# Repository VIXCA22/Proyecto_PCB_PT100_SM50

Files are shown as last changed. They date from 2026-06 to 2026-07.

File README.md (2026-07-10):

# Tarjeta de acondicionamiento de señales PT100 y SM-50

Diseño e implementación de una tarjeta de acondicionamiento de señales para sensores de torque y temperatura en un motor de inducción trifásico del LabCES. La PCB adapta las señales de un sensor de temperatura PT100 y un sensor de torque SM-50 para facilitar su adquisición y monitoreo dentro de un sistema de medición.

## Objetivo

Diseñar e implementar una tarjeta de circuito impreso que permita acondicionar y adaptar las señales provenientes de los sensores de torque y temperatura de un motor de inducción utilizado en el LabCES, con el propósito de facilitar su correcta adquisición y monitoreo para analizar el desempeño del motor.

## Objetivos específicos

1. Comprender los fundamentos básicos del diseño de tarjetas de circuito impreso y su aplicación al acondicionamiento de señales usando KiCad.
2. Verificar el funcionamiento de los sensores de torque y temperatura mediante simulaciones y pruebas experimentales.
3. Diseñar una PCB que integre el circuito necesario para acondicionar las señales de los sensores.
4. Implementar y probar el prototipo, evaluando su desempeño dentro del sistema de medición del motor de inducción en el LabCES.
5. Mantener un repositorio Git con archivos de diseño electrónico, documentación técnica e historial de desarrollo.

## Vista del diseño

### Esquemático KiCad

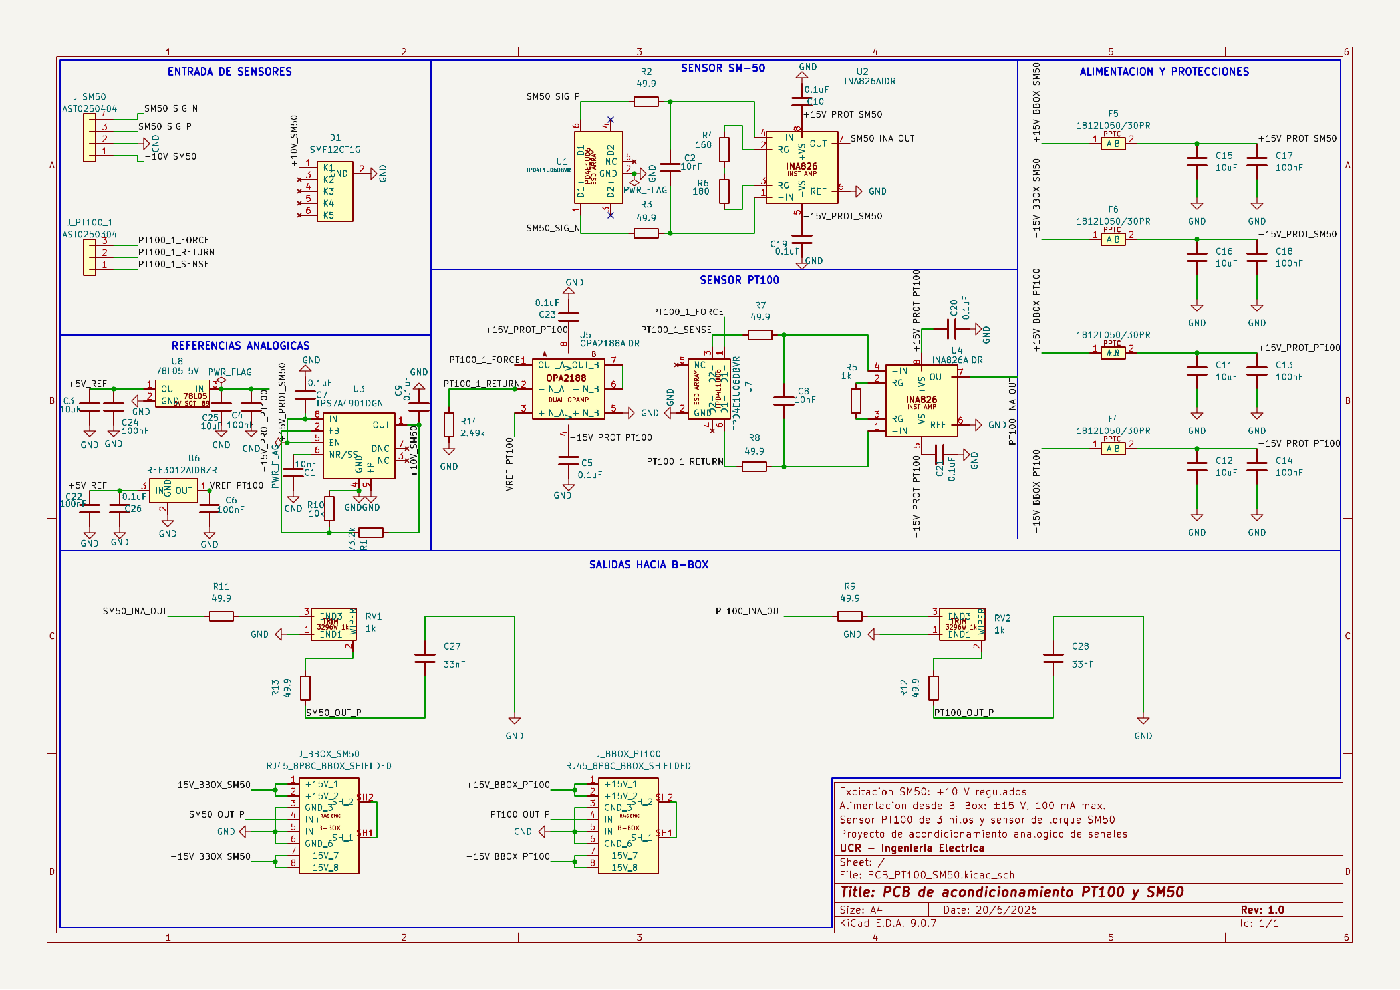
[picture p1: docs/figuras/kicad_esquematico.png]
Esquemático KiCad


### PCB en KiCad

<p align="center">
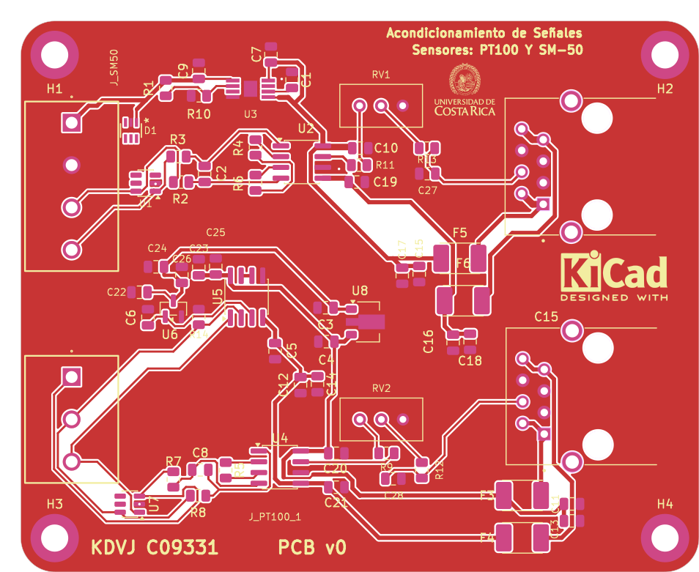
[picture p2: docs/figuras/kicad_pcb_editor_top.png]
PCB 2D
  
</p>

### PCB 3D

<p align="center">
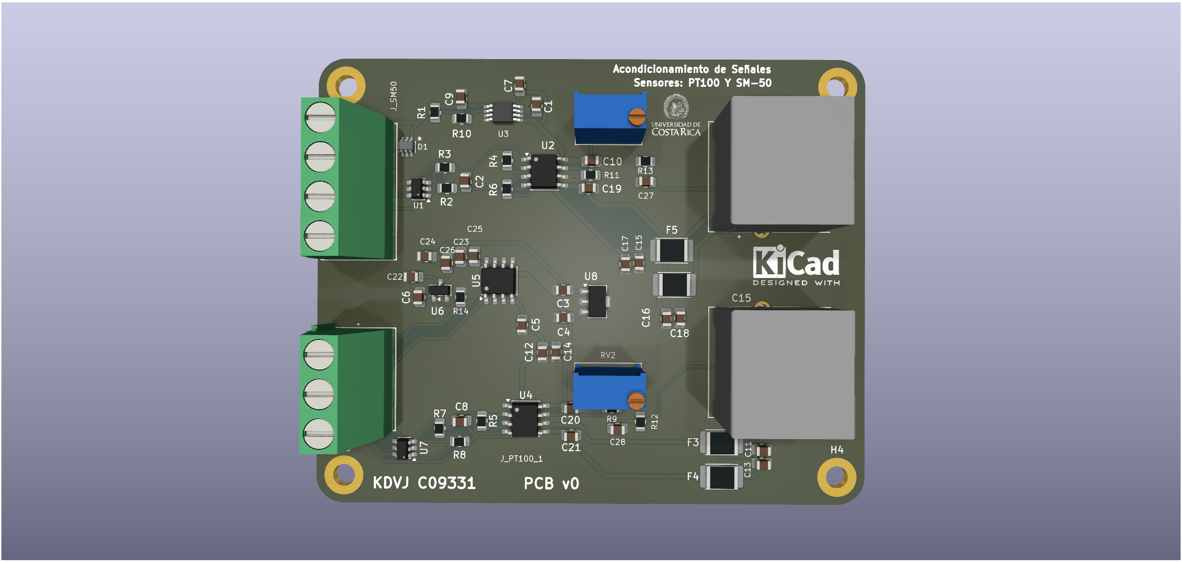
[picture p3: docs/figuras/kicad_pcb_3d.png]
PCB 3D
  
</p>

## Diagrama de bloques

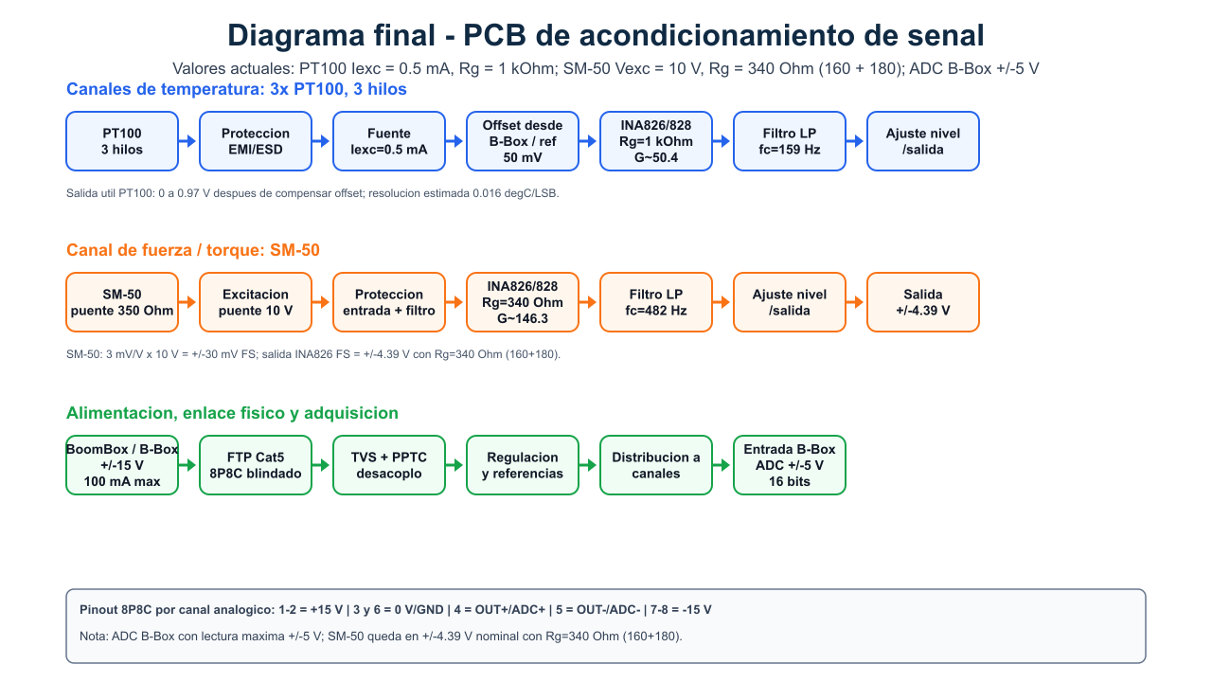
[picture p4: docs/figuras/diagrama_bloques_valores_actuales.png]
Diagrama de bloques


Nota de adquisicion: la lectura maxima del ADC de la B-Box se toma como +/-5 V (10 V de span), por lo que la salida bipolar nominal del SM-50 se mantiene en +/-4.39 V para conservar margen de medicion.

## Simulaciones

### Canal PT100

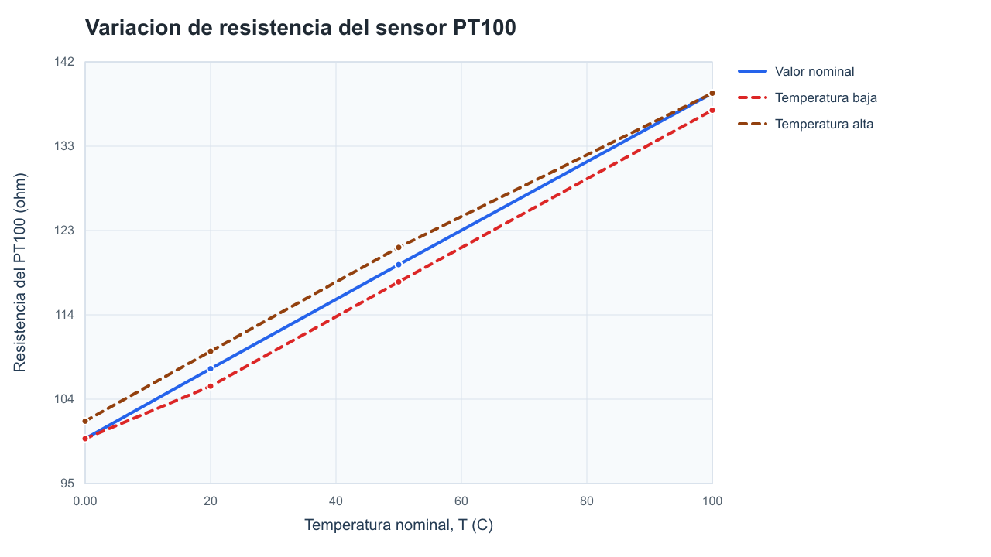
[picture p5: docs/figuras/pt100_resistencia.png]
Resistencia PT100


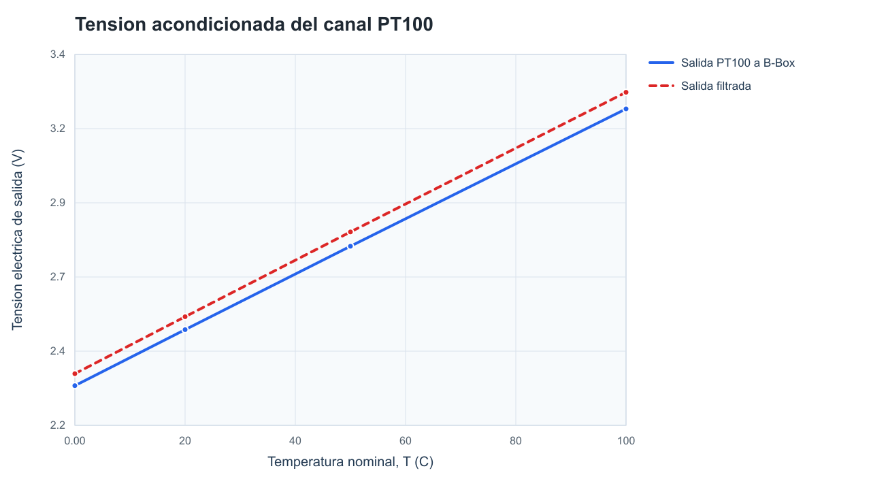
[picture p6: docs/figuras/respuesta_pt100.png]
Respuesta PT100


### Canal SM-50

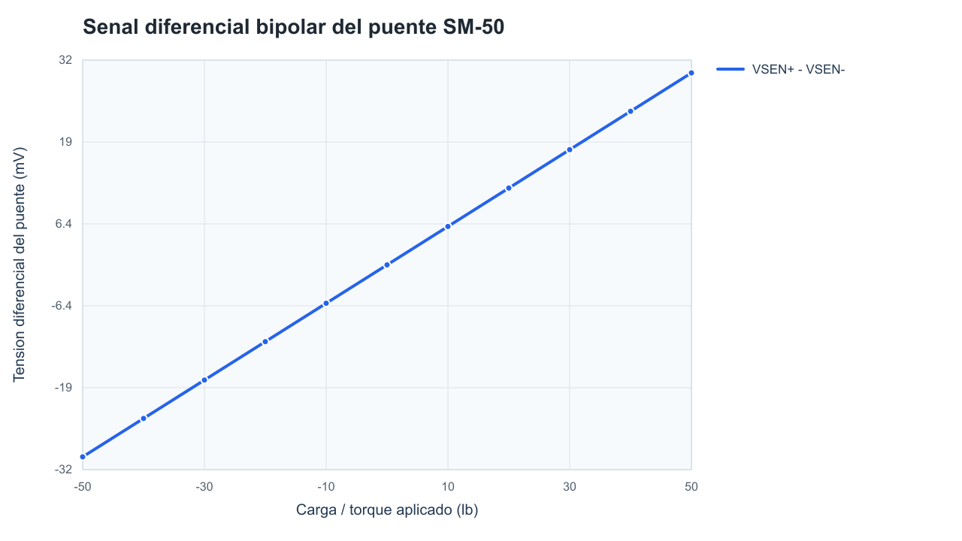
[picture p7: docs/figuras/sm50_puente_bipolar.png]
Puente SM-50 bipolar


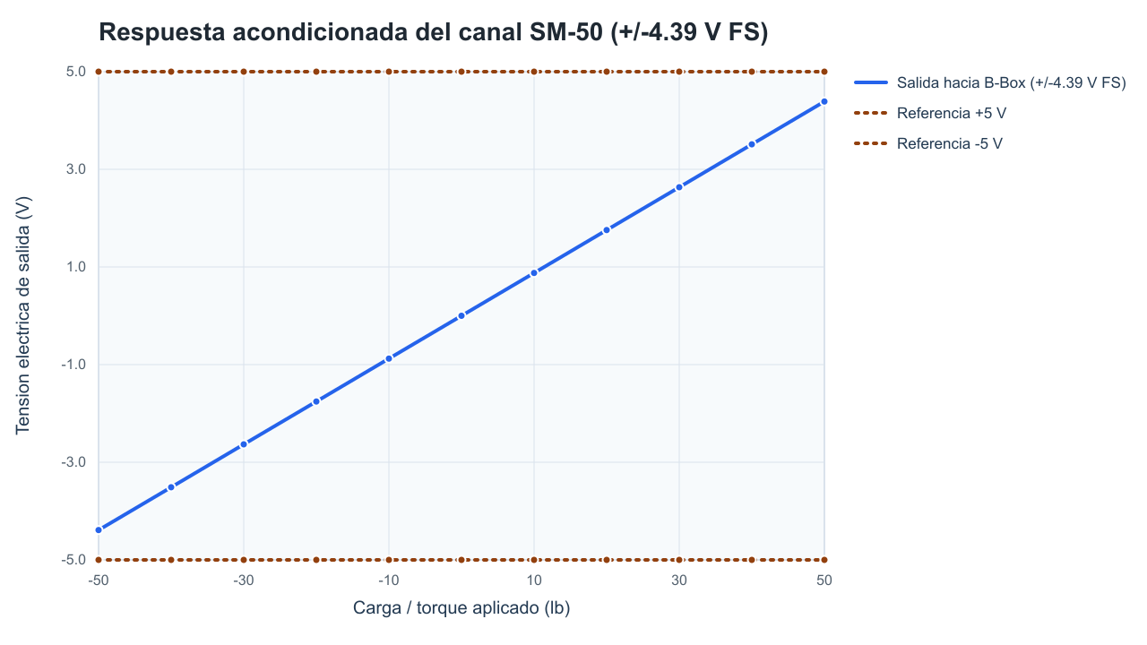
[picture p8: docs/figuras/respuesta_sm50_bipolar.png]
Respuesta SM-50 bipolar


### Esquemáticos LTspice

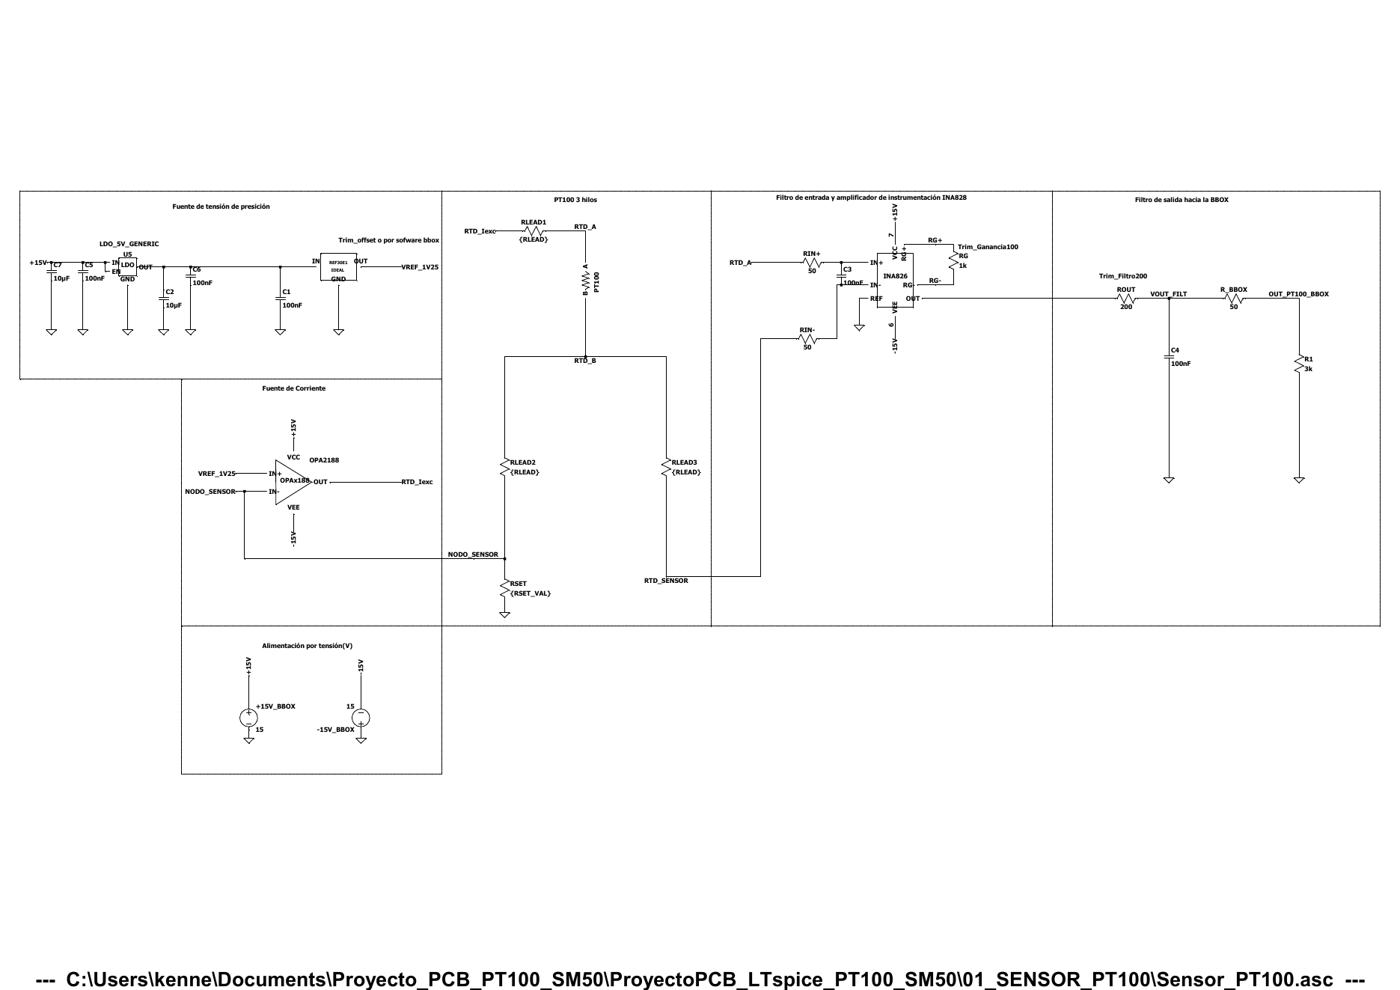
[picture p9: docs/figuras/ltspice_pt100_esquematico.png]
LTspice PT100


[PDF PT100](docs/figuras/ltspice_pt100_esquematico.pdf)

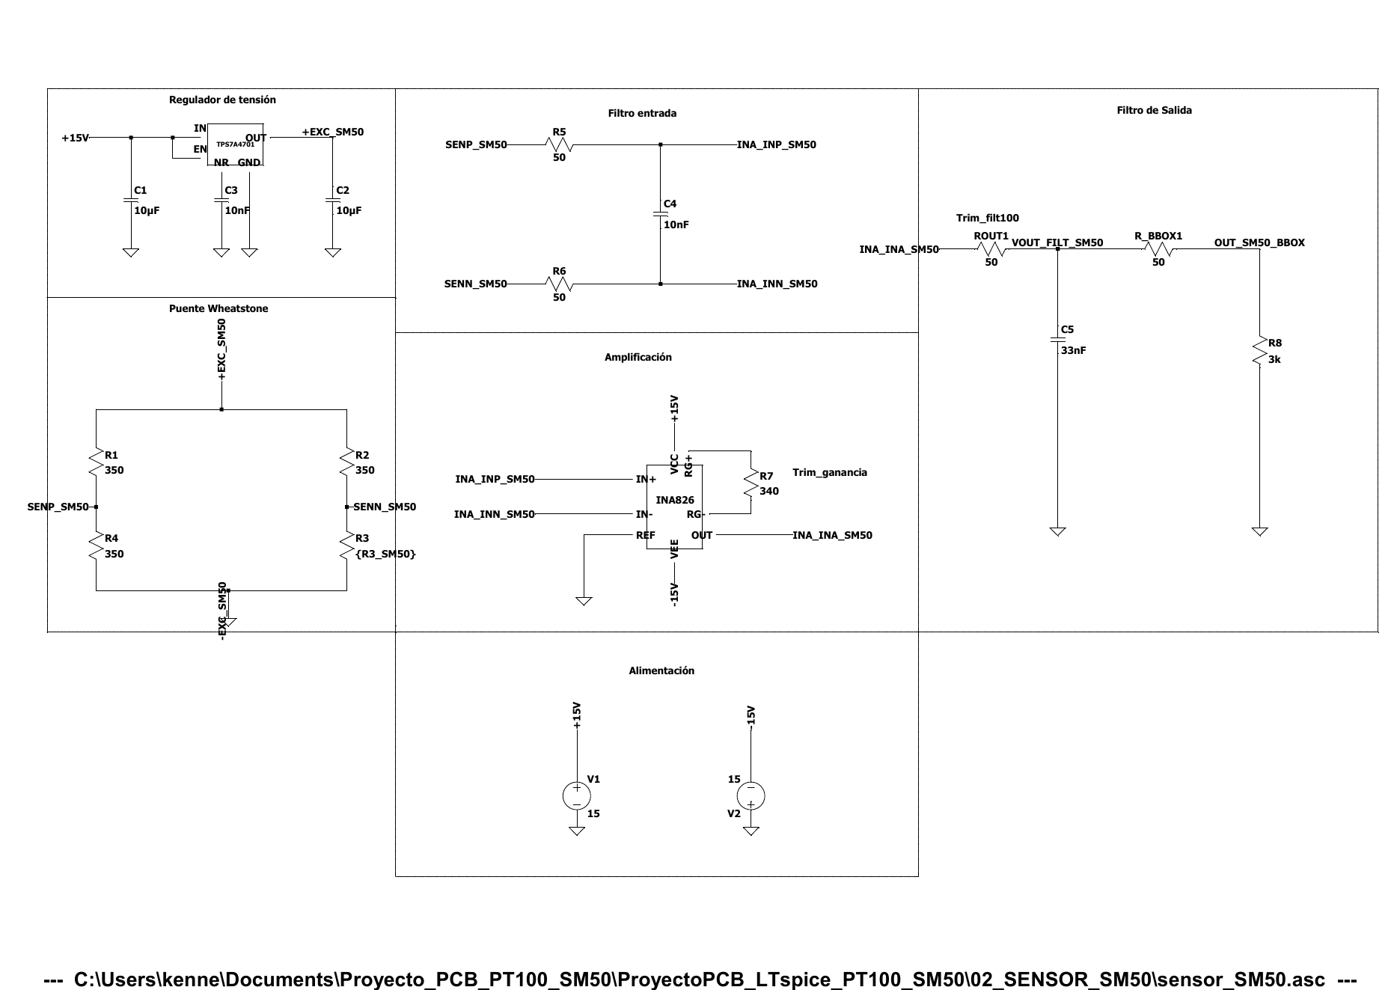
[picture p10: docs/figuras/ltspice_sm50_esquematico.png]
LTspice SM-50


[PDF SM-50](docs/figuras/ltspice_sm50_esquematico.pdf)

## Estructura del repositorio

| Ruta | Contenido |
| --- | --- |
| `PCB_PT100_SM50/` | Proyecto KiCad principal: esquemático, PCB, librerías locales, footprints y modelos 3D. |
| `ProyectoPCB_LTspice_PT100_SM50/` | Simulaciones LTspice de los canales PT100 y SM-50. |
| `docs/figuras/` | Imágenes/PDF del esquemático, PCB, vista 3D, LTspice y gráficas. |
| `docs/simulacion/` | CSV, resumen numérico y cálculos finales usados para las gráficas y tablas. |
| `docs/validacion/` | Reportes finales ERC/DRC. |
| `docs/fabricacion/` | ZIP Gerber final con archivo de taladros. |
| `docs/resumen/` | Resumen ejecutivo final del proyecto. |
| `docs/poster/` | Póster final usado para la presentación del proyecto. |
| `docs/bitacora/` | Bitácora actualizada del proceso, en PDF y fuente LaTeX. |
| `docs/referencias/` | Resumen de verificación de footprints y documentos de entrega conservados. |
| `scripts/` | Script para regenerar figuras de simulación y vistas documentales LTspice. |

## Estado final

- KiCad ERC: `0` errores, `0` advertencias.
- KiCad DRC: `0` violaciones, `0` pads desconectados, `0` errores de footprints.
- Paridad esquemático-PCB: `0` problemas.
- ZIP para fabricar: `docs/fabricacion/PCB_PT100_SM50_GERBERS_CON_DRILL.zip`.
- Reportes: `docs/validacion/erc_final_20260626.rpt` y `docs/validacion/drc_final_20260626.rpt`.

## Cómo revisar

1. Abrir `PCB_PT100_SM50/PCB_PT100_SM50.kicad_pro` en KiCad 9.
2. Ejecutar ERC desde el editor esquemático.
3. Ejecutar DRC con comprobación de paridad esquemático-PCB desde el editor PCB.
4. Revisar las simulaciones en `ProyectoPCB_LTspice_PT100_SM50/`.
5. Subir a fabricación el ZIP `docs/fabricacion/PCB_PT100_SM50_GERBERS_CON_DRILL.zip` si se requiere fabricar esta revisión.

## Documentación

- [Reporte formal IEEE PCB PT100/SM-50](docs/reporte_ieee/ReporteFormalPCB_PT100_SM50.pdf)
- [Informe de desarrollo del proyecto](docs/INFORME_DESARROLLO_PROYECTO.md)
- [Resumen ejecutivo](docs/resumen/ResumenEjecutivoKDVJC09331.pdf)
- [Proceso de diseño y trazabilidad](docs/PROCESO_DISENO_TRAZABILIDAD.md)
- [Bitácora actualizada del proyecto](docs/bitacora/bitacora_PCB_actualizada_27_06_2026.pdf)
- [Póster final](docs/poster/vizcaino-jimenez.pdf)
- [Validación final](docs/VALIDACION.md)
- [Referencias técnicas y footprints](docs/REFERENCIAS_TECNICAS.md)

## Herramientas

- KiCad 9.0.7
- LTspice
- Python 3 para generar figuras documentales
- Git / GitHub

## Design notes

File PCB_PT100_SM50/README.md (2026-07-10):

# Proyecto KiCad - PCB PT100 y SM-50

Esta carpeta contiene el diseno KiCad principal de la tarjeta de acondicionamiento de senales para sensores PT100 y SM-50.

## Archivos principales

| Archivo o carpeta | Uso |
| --- | --- |
| `PCB_PT100_SM50.kicad_pro` | Proyecto KiCad principal. |
| `PCB_PT100_SM50.kicad_sch` | Esquematico del circuito de acondicionamiento. |
| `PCB_PT100_SM50.kicad_pcb` | Layout de la PCB. |
| `symbols/` | Librerias de simbolos locales. |
| `footprints/` | Huellas locales usadas por la PCB. |
| `3d/` | Modelos 3D vinculados a las huellas. |
| `bom/` | Lista de materiales y referencia de compra. |
| `docs/` | Imagenes y soporte visual del diseno. |
| `outputs/` | Reportes de validacion generados por KiCad. |

## Estado de validacion

El cierre de validacion documentado fue generado con KiCad 9 y no reporta violaciones:

```text
../docs/validacion/erc_final_20260626.rpt
../docs/validacion/drc_final_20260626.rpt
```

La carpeta `outputs/` conserva reportes locales intermedios del PCB. Los reportes anteriores con warnings eran de sincronizacion de librerias, no de conexion electrica. Se registro la libreria faltante `ProyectoPCB` y se dejo la regla `lib_symbol_mismatch` en `ignore` porque varios simbolos fueron ajustados localmente para el esquematico.

## Uso rapido

1. Abrir `PCB_PT100_SM50.kicad_pro` en KiCad 9.
2. Revisar el esquematico y correr ERC.
3. Revisar el PCB y correr DRC antes de fabricar.
4. Usar las librerias locales incluidas en `sym-lib-table` y `fp-lib-table`.

## Nota sobre LTspice

Los archivos `.asy` y `.lib` pertenecen a simulacion LTspice. No se deben importar como simbolos o footprints KiCad; para KiCad se usan `.kicad_sym`, `.kicad_mod` y modelos `.step/.wrl`.

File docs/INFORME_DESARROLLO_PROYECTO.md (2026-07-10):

# Informe de desarrollo del proyecto

Fecha de redacción: 2026-06-27.

## Proyecto

Este proyecto consistió en diseñar y documentar una tarjeta de circuito impreso para el acondicionamiento de las señales de un sensor de temperatura PT100 y un sensor de carga/torque SM-50, pensada para integrarse al sistema de medición de un motor trifásico de inducción del LabCES. La tarjeta se planteó como una etapa intermedia entre los sensores instalados en el banco y la interfaz de adquisición, por lo que el diseño se enfocó en entregar señales de voltaje limpias, protegidas y dentro de rangos útiles para la B-Box o el sistema de adquisición disponible.

El punto de partida fue una investigación previa de LabCES orientada al cálculo de eficiencia de motores mediante el estándar IEEE 112, método C. En ese trabajo se identificó la necesidad de medir temperatura, velocidad, potencia y carga para estimar la eficiencia del motor bajo distintos puntos de operación. También se documentó que la temperatura se midió con sensores RTD instalados en los bobinados del estator y que la señal de carga requería una revisión cuidadosa, ya que durante pruebas previas el comportamiento del sensor no fue suficientemente confiable. Por esa razón, esta PCB se trabajó como una mejora de acondicionamiento y documentación, no como una prueba experimental final del banco.

## Fuentes usadas

| Fuente | Uso en el proyecto |
| --- | --- |
| `Proyecto_PCB_TODO_con_referencias.zip/00_INDICE_DE_ARCHIVOS.txt` | Índice del paquete completo de referencias, memorias, capturas, datasheets y bibliografía. |
| `Proyecto_PCB_TODO_con_referencias.zip/00_REFERENCIAS_IMPORTANTES.txt` | Bibliografía principal en formato LaTeX/bibitem para defender el proyecto. |
| `Proyecto_PCB_TODO_con_referencias.zip/calculos_memorias/memoria_calculo_PCB0.docx` | Memoria preliminar de cálculo para PT100 y SM-50; usada para documentar la evolución de los parámetros. |
| `Proyecto_PCB_TODO_con_referencias.zip/referencias_bibliografia/fuentes_pcb_sensores_motor.pdf` | Marco bibliográfico sobre PCB de acondicionamiento, sensores de torque/temperatura y motores de inducción. |
| `Proyecto_PCB_TODO_con_referencias.zip/instrumentacion_puentes_adc/sloa034.pdf` | Referencia de TI para acondicionamiento de sensores resistivos en puente Wheatstone. |
| `Proyecto_PCB_TODO_con_referencias.zip/instrumentacion_puentes_adc/sboa247a.pdf` | Referencia de TI para amplificación de puentes de galgas extensiométricas en una sola alimentación. |
| `Proyecto_PCB_TODO_con_referencias.zip/instrumentacion_puentes_adc/an43f.pdf` | Nota de Analog Devices sobre circuitos de puente. |
| `Proyecto_PCB_TODO_con_referencias.zip/instrumentacion_puentes_adc/an96fa.pdf` | Nota de Analog Devices sobre medición de puentes con ADC delta-sigma y consideraciones de ruido/resolución. |
| `Proyecto_PCB_TODO_con_referencias.zip/datasheets_sensores/Electrical_Wiring_Diagram.pdf` | Cableado de celdas de carga Interface, colores de cable, excitación y señales. |
| `Proyecto_PCB_TODO_con_referencias.zip/pcb_kicad_ruido_fabricacion/User-Manual-BoomBox.pdf` | Especificaciones prácticas de entradas analógicas BoomBox/B-Box, RJ45, Cat5e, alimentación de sensores y límites de entrada. |
| `paquete_memoria_PCB0_VALORES_ACTUALES_v3_referencias.zip/memoria_calculo_PCB0_VALORES_ACTUALES_v3_referencias_completas.pdf` | Memoria vigente de cálculo; reemplaza valores preliminares y fija los valores actuales de PT100, SM-50 e interfaz B-Box. |
| `docs/simulacion/calculos_PT100_SM50_VALORES_ACTUALES_v2.csv` | Tabla numérica regenerable con los cálculos finales de ambos sensores. |
| `docs/referencias/referencias_completas_proyecto_PCB.txt` | Índice de referencias finales, teóricas, de PCB y de trazabilidad usado para citar la memoria actual. |
| `docs/bitacora/bitacora_PCB_actualizada_27_06_2026.pdf` | Bitácora cronológica del trabajo realizado desde el 11/03/2026 hasta el 27/06/2026. |
| `Proyecto_eficiencia_LabCES-20260627T040051Z-3-001.zip/Reporte_final_P.pdf` | Contexto del banco de LabCES, estándar IEEE 112, método C, sensores usados y problemas encontrados en pruebas previas. |
| `Proyecto_eficiencia_LabCES-20260627T040051Z-3-001.zip/Caracterizacion_de_todo_los_sensores_y_lista_de_materiales.pdf` | Datos experimentales previos de PT100, salida de instrumentación y prueba de carga. |
| `Proyecto_eficiencia_LabCES-20260627T040051Z-3-001.zip/Interface-Book-2022-Edition.pdf` | Fundamento general de celdas de carga, galgas extensiométricas, excitación, sensibilidad y errores de montaje. |
| `C:/Users/kenne/Downloads/SM-S-Type.pdf` | Datos del sensor SM S-Type: salida nominal 3.0 mV/V, puente de 350 ohm y excitación máxima de 15 VDC. |
| `docs/simulacion/pt100_sweep_ng_20260625.csv` | Valores usados para las gráficas del canal PT100. |
| `docs/simulacion/sm50_sweep_bipolar_ng_20260629.csv` | Valores usados para las gráficas bipolares del canal SM-50. |
| `PCB_PT100_SM50/COMPONENTES_A_USAR_KICAD.csv` | Lista base de componentes, bloques funcionales y MPN seleccionados. |
| `ProyectoPCB_LTspice_PT100_SM50/03_KICAD_LIBS/AUDITORIA_FOOTPRINTS.md` | Trazabilidad de símbolos, footprints, modelos 3D y fuentes primarias revisadas. |
| `docs/VALIDACION.md` | Resultado final de ERC, DRC y paquete de fabricación. |

Los paquetes `Proyecto_PCB_TODO_con_referencias.zip` y `paquete_memoria_PCB0_VALORES_ACTUALES_v3_referencias.zip` se usaron como fuente documental, pero no se agregaron completos al repositorio para evitar subir archivos pesados y duplicados. En el repositorio se conserva la síntesis técnica, los datos numéricos regenerables, las referencias textuales y los archivos finales de diseño.

## Desarrollo por objetivos específicos

### 1. Comprensión del problema y fundamentos del acondicionamiento

Primero se delimitó el problema de medición. El banco del LabCES requiere variables eléctricas y mecánicas para evaluar el desempeño de un motor trifásico de inducción. Dentro de esas variables, la temperatura y la carga/torque requieren acondicionamiento porque no entregan directamente una señal de voltaje amplia y fácil de adquirir.

Para el PT100 se partió del comportamiento resistivo de un RTD. La resistencia aumenta con la temperatura, pero para convertir esa variación en voltaje hace falta excitar el sensor con una corriente estable. En el diseño final se usó una referencia de 1.25 V y una resistencia de ajuste de 2.49 kohm, lo que produce una corriente cercana a 0.5 mA. Esta corriente genera una caída de tensión sobre el PT100 que luego se amplifica y filtra.

Para el SM-50 se tomó como base el comportamiento de una celda de carga tipo puente de galgas extensiométricas. La hoja del sensor SM S-Type indica una salida nominal de 3.0 mV/V, resistencia de puente de 350 ohm y excitación máxima de 15 VDC. Con una excitación de 10 V, la señal diferencial esperada a escala completa queda alrededor de +/-30 mV. Por eso fue necesario usar un amplificador de instrumentación con ganancia ajustada, de forma que la salida bipolar nominal llegue a +/-4.39 V sin saturar.

### 2. Verificación mediante simulación

La verificación inicial se realizó en LTspice. Se separaron los canales para evitar que la depuración de un sensor afectara al otro:

| Canal | Archivo principal | Propósito |
| --- | --- | --- |
| PT100 | `ProyectoPCB_LTspice_PT100_SM50/01_SENSOR_PT100/Sensor_PT100.asc` | Simular la resistencia del RTD, la corriente de excitación, la amplificación y la salida hacia B-Box. |
| SM-50 | `ProyectoPCB_LTspice_PT100_SM50/02_SENSOR_SM50/sensor_SM50.asc` | Simular el puente de galgas, la excitación de 10 V, la ganancia del INA826 y la salida acondicionada. |

En el canal PT100 se usó el modelo cuadrático de resistencia para temperaturas positivas:

`R(T) = 100 * (1 + 3.9083e-3*T - 5.775e-7*T^2)`

La simulación barre temperaturas representativas y calcula tanto la resistencia nominal como las condiciones baja y alta usadas para visualizar variación. En el canal SM-50 se barrió la carga de -50 lb a +50 lb y se comparó la salida hacia B-Box contra las referencias de +/-5 V.

Las gráficas del repositorio se generaron desde los CSV en `docs/simulacion/`, no desde valores escritos a mano. Esto permite que las figuras sean repetibles.

### Evolución desde la memoria de cálculo preliminar

La memoria `memoria_calculo_PCB0.docx` fue importante para fijar el razonamiento inicial: calcular la sensibilidad del PT100, estimar autocalentamiento, separar offset de variación útil, calcular ganancia del amplificador de instrumentación, y dimensionar el canal SM-50 desde una señal de puente de aproximadamente 30 mV a escala completa. Sin embargo, esa memoria corresponde a una etapa previa del proyecto y no todos sus valores quedaron iguales en la revisión final.

La diferencia principal es el destino de la señal. En la memoria preliminar se pensó en aprovechar un ADC de 3.3 V directamente, mientras que el proyecto final se adaptó a la BoomBox/B-Box, cuya lectura máxima de ADC se toma como +/-5 V, equivalente a 10 V de span diferencial, y que entrega alimentación de sensores por el cable analógico. Por eso el canal SM-50 final usa una ganancia intermedia, suficiente para llevar la señal a un rango bipolar nominal de +/-4.39 V y dejar margen frente al límite de la B-Box. En el PT100 se redujo la corriente de excitación a 0.5 mA para disminuir autocalentamiento y mantener una respuesta de voltaje compatible con el rango documentado en simulación.

| Aspecto | Memoria preliminar | Revisión final vigente |
| --- | --- | --- |
| PT100, corriente de excitación | 1 mA | 0.5 mA, definida por REF3012 de 1.25 V y RSET de 2.49 kohm |
| PT100, salida objetivo | 0 a 3.3 V hacia ADC | Span útil aproximado de 0 a 0.970 V después de compensar offset; en la simulación LTspice la salida absoluta queda alrededor de 2.33 a 3.22 V |
| PT100, amplificador | INA828 como opción inicial | INA826 como cálculo principal; INA828 queda solo como equivalente si se monta |
| SM-50, sensibilidad base | 3 mV/V con 10 V, es decir cerca de 30 mV FS | Igual: 3 mV/V, puente de 350 ohm y excitación de 10 V |
| SM-50, ganancia calculada | Cerca de 100 V/V para salida de 3.3 V | `RG = 340 ohm` (`160 + 180 ohm`), `G = 146.29 V/V`, salida nominal de +/-4.39 V a escala completa |
| Interfaz de adquisición | ADC genérico de 3.3 V | BoomBox/B-Box con entrada diferencial de alta impedancia, ADC de 16 bits, lectura máxima +/-5 V y alimentación +/-15 V limitada a 100 mA |

Esta evolución no se considera una contradicción, sino una decisión de integración: se conservaron los fundamentos de sensibilidad, filtrado y amplificación diferencial, pero se recalcularon rangos para la interfaz real de adquisición.

### Cálculos finales de diseño

La memoria `memoria_calculo_PCB0_VALORES_ACTUALES_v3_referencias_completas.pdf` es la referencia vigente para los cálculos finales. Esa memoria separa las referencias finales de las memorias antiguas: la BoomBox/B-Box se cita como base de interfaz [F1], el datasheet del SM S-Type como base del sensor SM-50 [F2], el diagrama de cableado de Interface como base de conexión [F3], el modelo PT100/IEC 60751 como base del RTD [F4], y los datasheets INA826/INA828 como base de la ecuación de ganancia [F5]. Las notas SLOA034, SBOA247A, AN-43 y AN-96 se usan como soporte teórico para puentes Wheatstone, medición diferencial, ruido y acondicionamiento de señales pequeñas [T3]-[T6].

#### Interfaz BoomBox/B-Box

| Parámetro | Cálculo o dato usado | Resultado | Base |
| --- | --- | ---: | --- |
| Rango de medición | Entrada analógica en rango +/-5 V | 10 V de span | Manual BoomBox/B-Box [F1] |
| Resolución ADC | 16 bits | 65536 niveles | Manual BoomBox/B-Box [F1] |
| LSB en +/-5 V | `10 V / 2^16` | 152.59 uV/LSB | Manual BoomBox/B-Box [F1] |
| Alimentación disponible | Rieles por 8P8C | +/-15 V, 100 mA máx. | Manual BoomBox/B-Box [F1] |
| Entrada usada | Alta impedancia diferencial | 3 kohm diferencial | Manual BoomBox/B-Box [F1] |

#### Canal PT100

| Parámetro | Cálculo | Resultado | Base |
| --- | --- | ---: | --- |
| Modelo resistivo | `R(T)=R0*(1+alpha*T)` | Aproximación 0-100 degC | PT100/IEC 60751 [F4] |
| Resistencia a 0 degC | `R0` | 100.00 ohm | PT100/IEC 60751 [F4] |
| Coeficiente medio | `alpha` | 0.00385 1/degC | PT100/IEC 60751 [F4] |
| Resistencia a 100 degC | `100*(1+0.00385*100)` | 138.50 ohm | PT100/IEC 60751 [F4] |
| Variación útil | `138.50 - 100.00` | 38.50 ohm | Cálculo propio |
| Corriente de excitación | Valor final del diseño | 0.5 mA | Memoria v3 y criterio de autocalentamiento |
| Voltaje a 0 degC | `0.5 mA * 100 ohm` | 50.00 mV | Cálculo propio |
| Voltaje a 100 degC | `0.5 mA * 138.50 ohm` | 69.25 mV | Cálculo propio |
| Span eléctrico útil | `0.5 mA * 38.50 ohm` | 19.25 mV | Cálculo propio |
| Sensibilidad cruda | `0.5 mA * 0.385 ohm/degC` | 0.1925 mV/degC | Cálculo propio |
| Resistencia de ganancia | `RG = 1 kohm` | 1 kohm | Memoria v3 |
| Ganancia INA826 | `1 + 49.4 kohm / 1 kohm` | 50.40 V/V | Datasheet INA826 [F5] |
| Span amplificado | `50.40 * 19.25 mV` | 0.970 V | Cálculo propio |
| Sensibilidad de salida | `50.40 * 0.1925 mV/degC` | 9.702 mV/degC | Cálculo propio |
| Resolución estimada | `152.59 uV / 9.702 mV/degC` | 0.0157 degC/LSB | B-Box [F1] + cálculo |
| Potencia a 100 degC | `(0.5 mA)^2 * 138.50 ohm` | 34.62 uW | Cálculo propio |
| Autocalentamiento estimado | `34.62 uW / 2 mW/degC` | 0.0173 degC | Criterio conservador de disipación |
| Filtro pasabajo | `1/(2*pi*10 kohm*100 nF)` | 159.2 Hz | Cálculo RC |

#### Canal SM-50

| Parámetro | Cálculo | Resultado | Base |
| --- | --- | ---: | --- |
| Tipo de sensor | Puente Wheatstone | 350 ohm nominal | Datasheet SM S-Type [F2] |
| Excitación | Valor final del diseño | 10 V | Datasheet permite hasta 15 V [F2] |
| Corriente del puente | `10 V / 350 ohm` | 28.57 mA | Cálculo propio |
| Potencia del puente | `10^2 / 350` | 285.71 mW | Cálculo propio |
| Sensibilidad nominal | Rated output | 3.0 mV/V | Datasheet SM S-Type [F2] |
| Salida diferencial FS | `3 mV/V * 10 V` | 30.00 mV | Datasheet + cálculo |
| Rango usado | Valor de memoria v3 | 2.2 N*m | Memoria v3 |
| Sensibilidad cruda | `30.00 mV / 2.2 N*m` | 13.636 mV/N*m | Cálculo propio |
| Cambio para 0.01 N*m | `13.636 mV/N*m * 0.01` | 136.36 uV | Cálculo propio |
| Resistencia de ganancia | `RG = 160 ohm + 180 ohm` | 340 ohm | BOM/memoria v3 |
| Ganancia INA826 | `1 + 49.4 kohm / 340 ohm` | 146.29 V/V | Datasheet INA826 [F5] |
| Salida máxima nominal | `146.29 * 30.00 mV` | +/-4.39 V | Cálculo propio |
| Sensibilidad de salida | `146.29 * 13.636 mV/N*m` | 1.995 V/N*m | Cálculo propio |
| Resolución estimada | `152.59 uV / 1.995 V/N*m` | 76.5 uN*m/LSB | B-Box [F1] + cálculo |
| Zero balance | `+/-1 %RO` | +/-0.300 mV crudo; +/-0.044 V a la salida | Datasheet [F2] + cálculo |
| No linealidad | `+/-0.03 %FS` | +/-0.660 mN*m | Datasheet [F2] + cálculo |
| Histéresis | `+/-0.02 %FS` | +/-0.440 mN*m | Datasheet [F2] + cálculo |
| Filtro pasabajo | `1/(2*pi*10 kohm*33 nF)` | 482.3 Hz | Cálculo RC |

El cálculo nominal y las gráficas del SM-50 usan el mismo criterio vigente: `RG = 340 ohm`, ganancia `G = 146.29 V/V`, puente de +/-30 mV a escala completa y salida acondicionada de +/-4.39 V. La salida queda dentro del límite práctico de lectura +/-5 V de la entrada B-Box.

### 3. Diseño del esquemático en KiCad

Después de validar rangos en LTspice, el circuito se trasladó a KiCad. El esquemático final se organizó por bloques funcionales: alimentación, protección, canal PT100, canal SM-50, filtrado y salida hacia la B-Box.

En el bloque de alimentación se consideró la disponibilidad de rieles desde la B-Box y la necesidad de una excitación regulada para el SM-50. El regulador TPS7A4901 se seleccionó para generar la referencia de excitación positiva de 10 V del puente, manteniendo un margen adecuado frente al máximo permitido por el sensor. En el bloque PT100 se incorporó una referencia REF3012 de 1.25 V para establecer la corriente de excitación. El uso de OPA2188 se justificó por su baja deriva, mientras que el INA826 se usó como amplificador de instrumentación para señales diferenciales pequeñas.

El manual de la BoomBox/B-Box reforzó la decisión de usar conectores RJ45 blindados y cable Cat5e para la interfaz analógica. La entrada analógica puede configurarse como diferencial de alta impedancia o como entrada de baja impedancia, incluye ganancia y filtro programable, y el conector entrega rieles de alimentación para sensores. Para el diseño de esta PCB se tomaron como restricciones prácticas los rieles +/-15 V disponibles por el cable y la lectura máxima de ADC de aproximadamente +/-5 V; por eso el SM-50 se dimensionó con salida bipolar nominal de +/-4.39 V.

| Pin RJ45 BoomBox analógica | Función reportada en manual |
| ---: | --- |
| 1, 2 | +15 V para sensores |
| 3, 6 | 0 V |
| 4 | Entrada positiva / entrada de corriente |
| 5 | Entrada negativa / tierra |
| 7, 8 | -15 V para sensores |

El diagrama de cableado de Interface para celdas de carga también justificó mantener una entrada diferencial con líneas de excitación y señal separadas. En la PCB se llevó esa idea al conector SM-50 de 4 hilos: `+EXC_SM50`, `-EXC_SM50`, `SENP_SM50` y `SENN_SM50`.

| Bloque | Decisión tomada | Justificación |
| --- | --- | --- |
| PT100 | Excitación de aproximadamente 0.5 mA | Reduce autocalentamiento y genera una caída medible sobre el RTD. |
| PT100 | REF3012 como referencia de 1.25 V | Permite definir la corriente con una resistencia precisa. |
| PT100 | OPA2188 como operacional de precisión | Baja deriva, adecuado para señales lentas de temperatura. |
| PT100/SM-50 | INA826 como amplificador diferencial | Su ganancia se define con una sola resistencia: `G = 1 + 49.4 kohm/RG`. |
| SM-50 | Excitación de 10 V | Compatible con la hoja del SM S-Type y produce cerca de 30 mV a escala completa. |
| SM-50 | Rango de salida bipolar nominal de +/-4.39 V | Facilita la lectura por la B-Box y deja margen frente al límite esperado de +/-5 V. |
| Entradas/salidas | Filtros RC y protección | Reducen ruido y protegen ante transitorios o manipulación del banco. |

Las notas de aplicación SLOA034 y SBOA247A respaldan la arquitectura usada para el SM-50: un puente Wheatstone genera una señal diferencial pequeña, el amplificador de instrumentación rechaza el modo común y la ganancia se elige para escalar la señal al rango de lectura. La nota AN96 se usó como advertencia de diseño: aumentar la ganancia solo para llenar todo el ADC no siempre mejora la resolución, porque también entran ruido, deriva y limitaciones del frente analógico. En este proyecto la ganancia se eligió con una restricción práctica: obtener una salida cercana a 5 V a escala completa y dejar margen frente al límite de la B-Box.

### 4. Migración a PCB, footprints y fabricación

La migración a PCB se realizó en el proyecto `PCB_PT100_SM50/PCB_PT100_SM50.kicad_pro`. Se usaron librerías locales para no depender de rutas externas de KiCad y se auditaron los footprints contra componentes reales de la lista de compra. Esto fue importante porque varios archivos descargados de proveedores incluían modelos 3D, pero no siempre un footprint mecánico listo para fabricar.

Las borneras de sensores se cambiaron a METZ de paso 5.00 mm, correspondientes a AST0250304 para PT100 y AST0250404 para SM-50. Los integrados INA826AIDR y OPA2188AIDR quedaron con footprints SOIC-8 específicos y modelos 3D separados para evitar que un modelo equivocado se heredara desde un footprint genérico. El RJ45 de interfaz B-Box se trabajó con el modelo Bel Fuse 2250066-1 y se revisó el ajuste mecánico dentro de KiCad.

Durante el cierre se corrigieron advertencias de serigrafía, referencias superpuestas y reglas de texto. La validación final quedó con:

| Revisión | Resultado |
| --- | --- |
| ERC KiCad | 0 errores, 0 advertencias |
| DRC KiCad | 0 violaciones |
| Pads desconectados | 0 |
| Errores de footprint | 0 |
| Paquete Gerber | Incluye cobre, máscara, pasta, serigrafía, contorno, `.gbrjob`, `.drl` y mapa de taladros |

El ZIP listo para fabricación quedó en `docs/fabricacion/PCB_PT100_SM50_GERBERS_CON_DRILL.zip`.

### 5. Documentación y repositorio

El repositorio se dejó organizado para que el proyecto pueda abrirse, revisarse y fabricarse sin depender de archivos temporales. Las simulaciones LTspice se conservaron en `ProyectoPCB_LTspice_PT100_SM50/`, el proyecto KiCad principal en `PCB_PT100_SM50/`, las figuras en `docs/figuras/`, los CSV de resultados en `docs/simulacion/` y la salida de fabricación en `docs/fabricacion/`.

También se generaron imágenes del esquemático, PCB 2D, PCB 3D, esquemáticos LTspice y gráficas. Esto permite que el README explique visualmente el estado del proyecto sin obligar a abrir KiCad o LTspice.

## Datos usados en las gráficas

### Gráfica: resistencia del PT100

Fuente: `docs/simulacion/pt100_sweep_ng_20260625.csv`.

| Temperatura (degC) | R PT100 nominal (ohm) | R baja (ohm) | R alta (ohm) |
| ---: | ---: | ---: | ---: |
| 0 | 100.000000 | 100.000000 | 101.952706 |
| 20 | 107.793500 | 105.849456 | 109.734656 |
| 50 | 119.397125 | 117.470406 | 121.320956 |
| 100 | 138.505500 | 136.607656 | 138.505500 |

La resistencia nominal simulada coincide con el comportamiento esperado de un PT100: alrededor de 100 ohm a 0 degC y 138.5 ohm a 100 degC. Esta tabla también sirve para comparar la simulación con la caracterización previa, donde se reportaron promedios cercanos de 100 ohm, 107.793 ohm, 119.395 ohm y 138.5 ohm para 0, 20, 50 y 100 degC.

### Gráfica: respuesta eléctrica del PT100

Fuente: `docs/simulacion/pt100_sweep_ng_20260625.csv`.

| Temperatura (degC) | Salida hacia B-Box (V) | Salida filtrada (V) |
| ---: | ---: | ---: |
| 0 | 2.328272 | 2.367077 |
| 20 | 2.509540 | 2.551366 |
| 50 | 2.779427 | 2.825751 |
| 100 | 3.223866 | 3.277597 |

La salida aumenta con la temperatura y queda dentro de un rango de adquisición práctico. El objetivo no fue medir directamente la resistencia con un multímetro, sino convertir la variación del PT100 en un voltaje estable y filtrado.

### Gráfica: tensión diferencial del puente SM-50

Fuente: `docs/simulacion/sm50_sweep_bipolar_ng_20260629.csv`.

| Carga (lb) | Tensión diferencial del puente (mV) |
| ---: | ---: |
| -50 | -30.000000 |
| -40 | -24.000000 |
| -30 | -18.000000 |
| -20 | -12.000000 |
| -10 | -6.000000 |
| 0 | 0.000000 |
| 10 | 6.000000 |
| 20 | 12.000000 |
| 30 | 18.000000 |
| 40 | 24.000000 |
| 50 | 30.000000 |

La simulación reproduce el orden de magnitud esperado por la hoja del SM S-Type: una celda de 3.0 mV/V excitada con 10 V entrega +/-30 mV a escala completa.

### Gráfica: salida acondicionada del SM-50

Fuente: `docs/simulacion/sm50_sweep_bipolar_ng_20260629.csv`.

| Carga (lb) | Salida hacia B-Box (V) | Límite + (V) | Límite - (V) |
| ---: | ---: | ---: | ---: |
| -50 | -4.388824 | 5.000000 | -5.000000 |
| -40 | -3.511059 | 5.000000 | -5.000000 |
| -30 | -2.633294 | 5.000000 | -5.000000 |
| -20 | -1.755529 | 5.000000 | -5.000000 |
| -10 | -0.877765 | 5.000000 | -5.000000 |
| 0 | 0.000000 | 5.000000 | -5.000000 |
| 10 | 0.877765 | 5.000000 | -5.000000 |
| 20 | 1.755529 | 5.000000 | -5.000000 |
| 30 | 2.633294 | 5.000000 | -5.000000 |
| 40 | 3.511059 | 5.000000 | -5.000000 |
| 50 | 4.388824 | 5.000000 | -5.000000 |

La salida acondicionada es bipolar y alcanza aproximadamente +/-4.39 V a escala completa. Esto permite usar un rango cómodo de adquisición sin saturar la etapa de entrada de +/-5 V.

## Antecedente experimental usado como referencia

En esta etapa no se realizó una prueba experimental propia de la PCB final, porque el prototipo aún no se había fabricado ni probado en el banco. Para no presentar una validación inexistente, la parte experimental se redacta como antecedente documentado a partir de la investigación previa entregada en el ZIP.

El reporte previo describe que se instalaron sensores RTD en los bobinados del estator del motor de inducción. Después de la instalación se verificó la resistencia de los sensores y se concluyó que los valores eran congruentes con la temperatura ambiente. Luego se construyó un circuito de instrumentación en protoboard para convertir la variación del RTD en una señal de voltaje y se realizó un barrido de temperatura.

### Datos previos de PT100

Fuente: `Caracterizacion_de_todo_los_sensores_y_lista_de_materiales.pdf`.

| Temperatura (degC) | Resistencia promedio reportada (ohm) |
| ---: | ---: |
| 0 | 100.000 |
| 20 | 107.793 |
| 50 | 119.395 |
| 100 | 138.500 |

Estos valores fueron útiles como referencia porque coinciden con el comportamiento esperado del modelo PT100 usado en la simulación. Por lo tanto, aunque no reemplazan una calibración de la PCB final, sí justifican que el rango de resistencia elegido para la simulación es razonable.

### Datos previos de salida de instrumentación

Fuente: `Caracterizacion_de_todo_los_sensores_y_lista_de_materiales.pdf`.

| Temperatura medida (degC) | Salida de instrumentación previa (V) |
| ---: | ---: |
| 40 | 2.00 |
| 50 | 2.03 |
| 60 | 2.36 |
| 70 | 2.73 |
| 80 | 3.03 |
| 90 | 3.30 |
| 100 | 3.50 |
| 110 | 3.80 |
| 120 | 4.20 |
| 130 | 4.38 |

La tendencia del antecedente fue creciente y aproximadamente lineal, lo cual respalda la idea de convertir la variación resistiva del PT100 en una señal analógica. La PCB actual no copia exactamente ese circuito, ya que reemplaza la etapa de protoboard por una solución con referencia estable, amplificadores de precisión, filtros y protección.

### Datos previos de carga

Fuente: `Caracterizacion_de_todo_los_sensores_y_lista_de_materiales.pdf`.

| Porcentaje | Carga nominal (lb) | Carga nominal (kg) | Carga real aplicada (lb) | Carga real aplicada (kg) | Voltaje medido (mV) |
| ---: | ---: | ---: | ---: | ---: | ---: |
| 0 | 0 | 0.00000 | 0.00000 | 0.000 | 0.0 |
| 20 | 10 | 4.53592 | 2.77341 | 1.258 | -83.6 |
| 40 | 20 | 9.07184 | 11.09585 | 5.033 | -77.1 |
| 60 | 30 | 13.60776 | 19.27499 | 8.743 | -70.6 |
| 80 | 40 | 18.14368 | 30.40832 | 13.793 | -61.8 |
| 100 | 50 | 22.67960 | 38.60290 | 17.510 | -55.7 |

El reporte previo indica que la medición de carga presentó comportamiento oscilante y no completamente confiable. Por eso estos datos se usaron solo como referencia histórica del banco, no como calibración del canal SM-50 de la PCB. La decisión técnica fue simular el SM-50 desde su sensibilidad nominal de mV/V y dejar la calibración experimental como una tarea posterior a la fabricación.

## Alcance experimental y trabajo pendiente

La parte experimental propia de esta revisión queda pendiente. Lo que sí se completó fue:

- Simulación eléctrica de ambos canales.
- Esquemático KiCad actualizado.
- PCB con footprints revisados.
- Modelos 3D y vistas para documentación.
- Validación ERC/DRC sin errores.
- Paquete Gerber con taladros listo para fabricar.

Después de fabricar la PCB, la validación recomendada es:

1. Alimentar la tarjeta desde la B-Box o fuente equivalente y verificar rieles.
2. Medir la excitación del SM-50 y confirmar los 10 V antes de conectar el sensor.
3. Probar el canal PT100 con resistencias patrón o caja de décadas antes del sensor real.
4. Registrar la salida del PT100 frente a temperaturas conocidas y ajustar la curva de calibración.
5. Probar el SM-50 con masas conocidas, evitando cargas laterales y momentos mecánicos.
6. Ajustar la ganancia del canal SM-50 si la salida se acerca demasiado a 5 V.
7. Repetir las mediciones para estimar repetibilidad, error y dispersión.

## Conclusiones

El proyecto avanzó desde una necesidad experimental del banco de eficiencia del LabCES hasta una tarjeta PCB documentada y lista para fabricación. Las referencias previas sirvieron para entender el contexto del motor, el método IEEE 112, la instalación de sensores y los problemas reales encontrados durante ensayos anteriores. Las hojas de datos y documentos técnicos permitieron convertir ese contexto en decisiones concretas de diseño: excitación estable para PT100, acondicionamiento de señales diferenciales con INA826, excitación de 10 V para el SM-50, protección de entradas/salidas y selección de footprints compatibles con los componentes comprados.

La validación experimental final no se reporta como realizada. En su lugar, se deja una validación por simulación, verificación de diseño y referencia a la investigación previa. Esto mantiene la trazabilidad honesta del proyecto: la PCB está preparada para fabricarse y probarse, pero sus curvas definitivas de calibración deben obtenerse con el hardware real en laboratorio.

## Bibliografía y referencias

- `Proyecto_PCB_TODO_con_referencias.zip`, paquete completo de referencias bibliográficas, memoria de cálculo, datasheets, capturas, notas de instrumentación y documentos de PCB/fabricación.
- `paquete_memoria_PCB0_VALORES_ACTUALES_v3_referencias.zip`, paquete final con memoria de cálculo vigente, CSV de valores actuales, diagrama de bloques y referencias completas.
- `docs/bitacora/bitacora_PCB_actualizada_27_06_2026.pdf`, bitácora actualizada del proceso desde el 11 de marzo de 2026 hasta el 27 de junio de 2026.
- `memoria_calculo_PCB0_VALORES_ACTUALES_v3_referencias_completas.pdf`, memoria vigente de cálculo para PT100, SM-50 e interfaz BoomBox/B-Box.
- `docs/simulacion/calculos_PT100_SM50_VALORES_ACTUALES_v2.csv`, tabla de cálculos finales usada para las tablas de este informe.
- `docs/referencias/referencias_completas_proyecto_PCB.txt`, listado de referencias finales, teóricas, de PCB y de trazabilidad.
- `memoria_calculo_PCB0.docx`, "Memoria de cálculo PCB de Acondicionamiento de Señal Sensores PT100 y SM-50", archivo incluido en `Proyecto_PCB_TODO_con_referencias.zip`.
- `fuentes_pcb_sensores_motor.pdf`, "Fuentes para el desarrollo de una PCB de acondicionamiento de sensores de torque y temperatura en motores de inducción", archivo incluido en `Proyecto_PCB_TODO_con_referencias.zip`.
- Ignacio Soto Montero, `Reporte_final_P.pdf`, "Pruebas de laboratorio para el cálculo de eficiencia en motores trifásicos de inducción", archivo incluido en `Proyecto_eficiencia_LabCES-20260627T040051Z-3-001.zip`.
- `Caracterizacion_de_todo_los_sensores_y_lista_de_materiales.pdf`, archivo incluido en `Proyecto_eficiencia_LabCES-20260627T040051Z-3-001.zip`.
- [T8] Interface, `Interface-Book-2022-Edition.pdf`, archivo incluido en `Proyecto_eficiencia_LabCES-20260627T040051Z-3-001.zip`.
- [F2] Interface, `SM-S-Type.pdf`, hoja de datos del sensor SM S-Type, archivo local en `C:/Users/kenne/Downloads/`.
- [F3] Interface, `Electrical_Wiring_Diagram.pdf`, diagrama eléctrico y cableado de celdas de carga, archivo incluido en `Proyecto_PCB_TODO_con_referencias.zip`.
- [F1] imperix, `User-Manual-BoomBox.pdf`, manual de la plataforma BoomBox/B-Box, archivo incluido en `Proyecto_PCB_TODO_con_referencias.zip`.
- [T3] Texas Instruments, "Signal Conditioning Wheatstone Resistive Bridge Sensors", SLOA034: https://www.ti.com/lit/an/sloa034/sloa034.pdf
- [T4] Texas Instruments, "Single-Supply Strain Gauge Bridge Amplifier Circuit", SBOA247A: https://www.ti.com/lit/pdf/sboa247
- [T5] Analog Devices, "AN-43: Bridge Circuits": https://www.analog.com/en/resources/app-notes/an-43f.html
- [T6] Analog Devices, "AN-96: Delta Sigma ADC Bridge Measurement Techniques": https://www.analog.com/en/resources/app-notes/an-96fa.html
- [F5] Texas Instruments, INA826 datasheet: https://www.ti.com/lit/ds/symlink/ina826.pdf
- Texas Instruments, OPA2188 datasheet: https://www.ti.com/lit/ds/symlink/opa2188.pdf
- Texas Instruments, TPS7A49/TPS7A4901 datasheet: https://www.ti.com/lit/ds/symlink/tps7a49.pdf
- Texas Instruments, REF30/REF30E datasheet: https://www.ti.com/lit/ds/symlink/ref30e.pdf
- [F4] PT100 Datasheet / ALLDATASHEET e IEC 60751, referencia del elemento RTD PT100 y modelo resistivo `R(T)`.
- [T1] R. Pallas-Areny, O. Casas y R. Bragós, `Sensores y acondicionadores de señal: Problemas resueltos`, base teórica para sensibilidad, offset, linealidad, sensores resistivos y puentes.
- [T2] Measurement Computing Corporation, `Signal Conditioning & PC-Based Data Acquisition Handbook`, base práctica para acondicionamiento, entradas diferenciales, RTD, strain gages, filtros, CMRR y ruido.
- Documentación interna del repositorio: `docs/PROCESO_DISENO_TRAZABILIDAD.md`, `docs/REFERENCIAS_TECNICAS.md`, `docs/VALIDACION.md` y `ProyectoPCB_LTspice_PT100_SM50/03_KICAD_LIBS/AUDITORIA_FOOTPRINTS.md`.

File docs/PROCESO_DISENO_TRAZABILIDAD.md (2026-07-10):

# Proceso de diseño y trazabilidad

Este documento resume cómo se llegó al resultado final del proyecto y registra las decisiones técnicas tomadas durante la revisión del diseño.

## 1. Definición del problema

El proyecto busca acondicionar las señales de dos sensores instalados en un motor de inducción del LabCES:

- PT100 para temperatura.
- SM-50 para torque.

La tarjeta debe entregar señales compatibles con el sistema de adquisición, manteniendo protección de entradas, referencia estable, alimentación analógica, filtrado y salida hacia B-Box.

## 2. Simulación de los sensores

Se desarrollaron simulaciones LTspice por canal:

- `ProyectoPCB_LTspice_PT100_SM50/01_SENSOR_PT100/`
- `ProyectoPCB_LTspice_PT100_SM50/02_SENSOR_SM50/`

Las simulaciones permitieron revisar la respuesta esperada antes de pasar al PCB:

- PT100: barrido de temperatura y salida acondicionada.
- SM-50: salida contra carga/torque relativo con distintas resistencias de ganancia.

Las gráficas finales se generaron desde CSV en `docs/simulacion/`.

## 3. Migración a KiCad

El diseño se trasladó a KiCad integrando:

- Esquemático principal.
- Librerías locales de símbolos.
- Footprints locales y footprints verificados contra fabricante.
- Modelos 3D para revisión mecánica.
- PCB con conectores para sensores y salidas hacia B-Box.

Proyecto principal:

`PCB_PT100_SM50/PCB_PT100_SM50.kicad_pro`

## 4. Revisiones que guiaron el cierre

Durante la depuración se hicieron revisiones iterativas enfocadas en:

- Corregir errores DRC sin romper el esquemático.
- Mantener las referencias visibles en Gerber y PDF de ensamble.
- Reducir o mover referencias cuando el espacio era limitado.
- Activar referencias deshabilitadas.
- Verificar footprints descargados contra BOM y datasheets.
- Dejar las borneras con modelo 3D verde manteniendo el footprint.
- Generar un ZIP Gerber válido con archivo de taladros `.drl`.
- Preparar un repositorio GitHub limpio, sin respaldos ni salidas pesadas.

## 5. Correcciones finales aplicadas

- Reubicación de referencias de serigrafía para eliminar advertencias DRC.
- Uso de altura mínima de 0.8 mm para referencias en zonas estrechas.
- Verificación de borneras METZ AST0250304/AST0250404.
- Confirmación de footprints SOIC-8 para INA826AIDR y OPA2188AIDR.
- Actualización del footprint/modelo 3D del TVS SMF12CT1G.
- Generación de imágenes para GitHub: KiCad esquemático, PCB 2D, PCB 3D, LTspice y gráficas.
- Regeneración del ZIP Gerber con taladros.

## 6. Bitácora del proceso

La bitácora actualizada se conserva en:

- `docs/bitacora/bitacora_PCB_actualizada_27_06_2026.pdf`
- `docs/bitacora/bitacora_PCB_actualizada_27_06_2026.tex`

Este documento registra el avance desde el 11/03/2026 hasta el 27/06/2026. La secuencia de trabajo se puede resumir así:

| Periodo | Actividad principal | Resultado para el proyecto |
| --- | --- | --- |
| 11/03/2026-18/03/2026 | Inicio, aprendizaje de KiCad, práctica de PCB y revisión de reglas básicas de diseño. | Se definió el alcance inicial y se estableció el flujo de esquemático, footprint y PCB. |
| 25/03/2026-30/03/2026 | Estudio de ruido, sensores y revisión técnica. | Se identificó la necesidad de filtrado, blindaje, cableado adecuado y acondicionamiento diferencial. |
| 08/04/2026-24/04/2026 | Arquitectura del sistema, validación previa de sensores y ajuste de adquisición. | Se separaron los bloques de temperatura, torque, adquisición e interfaz. |
| 29/04/2026-15/05/2026 | Revisión de hojas de datos, puente Wheatstone, rango dinámico, offset y resolución. | Se consolidaron las fórmulas base para PT100, SM-50 y salida hacia la interfaz de adquisición. |
| 19/05/2026-28/05/2026 | Validación de datos reales del SM-50, memoria de cálculo y revisión de interfaz BoomBox/B-Box. | Se fijaron criterios de excitación, ganancia, resolución y conexión física. |
| 31/05/2026-07/06/2026 | Alimentación, conectores, RJ45, organización funcional y PT100 de tres hilos. | Se definieron conectores de sensor, salidas 8P8C, bloques de PCB y criterios de referencia. |
| 08/06/2026-21/06/2026 | Depuración del PT100, referencias técnicas, LTspice, selección de amplificadores, EMI e integración KiCad. | Se cerró la arquitectura eléctrica y se pasó a implementación formal del esquemático. |
| 22/06/2026-27/06/2026 | Protecciones, footprints, ruteo, valores finales, memoria, referencias y fabricación. | Se obtuvo una PCB con ERC/DRC limpios, figuras finales, cálculos actualizados y paquete Gerber. |

La bitácora se usa como evidencia de proceso. Los cálculos finales vigentes son los conservados en `docs/simulacion/calculos_PT100_SM50_VALORES_ACTUALES_v2.csv` y en la memoria final citada en `docs/referencias/referencias_completas_proyecto_PCB.txt`.

## 7. Resultado

El repositorio queda preparado con fuentes, documentación, figuras y reportes finales. Los archivos de salida intermedios, respaldos y paquetes descargados de verificación se excluyen por `.gitignore` o fueron eliminados cuando eran regenerables.

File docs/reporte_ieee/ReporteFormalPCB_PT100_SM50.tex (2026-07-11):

\pdfminorversion=7
\documentclass[conference]{IEEEtran}
\IEEEoverridecommandlockouts

\usepackage[utf8]{inputenc}
\usepackage[T1]{fontenc}
\usepackage[spanish,es-tabla]{babel}
\usepackage{cite}
\usepackage{amsmath,amssymb}
\usepackage{graphicx}
\usepackage{booktabs}
\usepackage{array}
\usepackage{url}
\usepackage{xcolor}
\usepackage{float}
\usepackage{multicol}

\graphicspath{{../figuras/}}
\setlength{\textfloatsep}{7pt}
\setlength{\floatsep}{6pt}
\setlength{\intextsep}{6pt}

\begin{document}

\title{Diseño e implementación de una tarjeta de acondicionamiento de señales para sensores de torque y temperatura en un motor de inducción}

\author{\IEEEauthorblockN{Kenneth Daniel Vizcaíno Jiménez}
\IEEEauthorblockA{\textit{Escuela de Ingeniería Eléctrica}\\
\textit{Universidad de Costa Rica}\\
San José, Costa Rica\\
kenneth.vizcaino@ucr.ac.cr}}

\maketitle

\begin{abstract}
Este reporte documenta el diseño de una tarjeta de acondicionamiento para sensores de torque y temperatura instalados en un motor de inducción del LabCES. El propósito del proyecto es adaptar las señales de un PT100 y una celda SM-50 para facilitar su adquisición y monitoreo en el banco de pruebas. El trabajo partió de modelos eléctricos, se verificó en LTspice y se trasladó a KiCad para obtener una PCB lista para fabricación. El PT100 se excitó con baja corriente para reducir autocalentamiento y el SM-50 se amplificó hasta $\pm4.39$ V, dentro del rango de $\pm5$ V de la B-Box. El resultado actual incluye simulaciones, esquemático, PCB, validación ERC/DRC y paquete Gerber; la prueba con prototipo físico queda como cierre posterior.
\end{abstract}

\begin{IEEEkeywords}
PT100, SM-50, motor de inducción, puente Wheatstone, INA826, LTspice, KiCad, acondicionamiento de señal, B-Box.
\end{IEEEkeywords}

\section{Introducción}

El proyecto nace de una necesidad práctica: medir temperatura y torque en un motor trifásico de inducción sin depender de señales crudas, pequeñas o vulnerables al ruido. En el banco del LabCES, estas variables apoyan el análisis del desempeño del motor, por lo que la PCB se planteó como una etapa intermedia entre los sensores y la interfaz de adquisición. El objetivo general propuesto fue diseñar e implementar una tarjeta de circuito impreso que acondicione y adapte esas señales para facilitar su adquisición y monitoreo.

La propuesta se organizó alrededor de cuatro objetivos específicos: comprender el diseño de PCB aplicado al acondicionamiento de señales con KiCad; verificar los sensores mediante pruebas o antecedentes reales disponibles; diseñar la PCB del circuito de acondicionamiento; e implementar y probar el prototipo dentro del sistema del motor. Como entregables se propusieron repositorio Git, diseño completo, prototipo físico, manual de instalación y uso, y sistema probado en el banco del LabCES.

Este documento reporta el estado técnico alcanzado: diseño electrónico completo, simulación, justificación de valores, diseño en KiCad y paquete de fabricación. Los entregables que dependen de una PCB ensamblada se presentan como pendientes de validación experimental, no como resultados ya ejecutados.

\section{Criterios de diseño}

La ruta de señal se definió siguiendo la arquitectura recomendada para sensores resistivos: excitación estable, transductor, amplificación, filtrado y adquisición. Analog Devices resume esta idea para sensores de fuerza y temperatura, indicando que las señales de puentes y RTD requieren una cadena que cuide excitación, ganancia, ruido, rechazo de modo común y ancho de banda antes de llegar al ADC \cite{adi_paths}. Por eso la tarjeta no se diseñó como una suma de bloques sueltos, sino como dos rutas completas: PT100--referencia--amplificación--filtro--B-Box y SM-50--excitación--INA--filtro--B-Box.

La restricción de adquisición más importante fue el rango de entrada de la BoomBox/B-Box. La documentación de imperix reporta entradas analógicas diferenciales de $\pm5$ V y alimentación de sensores de $\pm15$ V limitada a 100 mA por el cable analógico \cite{imperix}. Con ese dato, el diseño no se planteó para llegar exactamente a $\pm5$ V, sino para quedar cerca y conservar margen frente a tolerancias, offset y calibración.

La misma revisión de la BoomBox justificó la interfaz física. El conector analógico entrega alimentación, tierra y entradas diferenciales en un cable tipo 8P8C, por lo que la PCB se diseñó con conectores RJ45 blindados, protección de entrada/salida y retornos separados. Así la tarjeta no solo adapta niveles eléctricos, sino que también respeta la forma de conexión del sistema de adquisición usado en el banco.

Para el PT100 se usó la relación de resistencia de un RTD de platino según IEC 60751: a 100 $^\circ$C se espera cerca de 138.5 $\Omega$ \cite{bipm}. La excitación se fijó en 0.5 mA con una referencia REF3012 de 1.25 V \cite{ref30} y una resistencia de 2.49 k$\Omega$, un valor moderado que produce señal medible sin calentar el sensor más de lo necesario. Los cálculos completos se dejaron en el Anexo A.

Para el SM-50 se partió de su naturaleza de puente de galgas: 350 $\Omega$, salida nominal de 3 mV/V y uso en tensión/compresión \cite{interface}. Con 10 V de excitación se obtienen 30 mV diferenciales a escala completa, por lo que se usó el INA826 para llevar la señal a $\pm4.39$ V con $R_G=340~\Omega$ \cite{ina826}. Esta arquitectura coincide con notas de TI y Analog Devices sobre puentes Wheatstone: excitar el puente, medir diferencialmente con rechazo de modo común y filtrar antes de adquirir \cite{sloa034}, \cite{sboa247}, \cite{an43}. También se evitó subir la ganancia sin criterio, porque el ruido y la deriva entran al mismo frente analógico \cite{an96}.

\subsection{Justificación numérica de los valores}

En el canal PT100, Analog Devices y Texas Instruments muestran que una medición RTD se suele resolver con corriente de excitación, referencia estable, ganancia y ADC de precisión \cite{adi_rtd}, \cite{ti_rtd}. El valor de 0.5 mA se defendió por sensibilidad suficiente, autocalentamiento bajo y compatibilidad con la B-Box. El span amplificado fue de aproximadamente 0.970 V entre 0 y 100 $^\circ$C; el detalle numérico está en el Anexo A.

En el canal SM-50, la hoja del sensor fija los tres datos de partida: 3.0 mV/V, puente de 350 $\Omega$ y excitación máxima de 15 VDC \cite{interface}. Se eligió 10 V porque genera 30 mV diferenciales a escala completa, mantiene la corriente del puente en 28.6 mA y evita subir la disipación del sensor al caso de 15 V. La ganancia necesaria para llevar esa señal a un rango cercano a $\pm4.4$ V coincide con el INA826 usando $R_G=340~\Omega$. Esta forma de escoger la ganancia sigue el criterio de diseños de puente ya publicados: primero se define el swing de salida permitido por el ADC y luego se calcula la ganancia desde el diferencial máximo esperado \cite{sboa247}.

Los filtros también se escogieron con una idea de ruta de señal, no solo por costumbre. ADI recomienda limitar el ancho de banda cuando el transductor es lento y sensible al ruido \cite{adi_paths}. Por eso se usaron filtros RC de salida: para PT100 se dejó un corte cercano a 159 Hz y para SM-50 uno cercano a 482 Hz. Ambos valores son suficientemente altos para no borrar la dinámica esperada del banco, pero reducen ruido antes de la adquisición. Las fórmulas de corte y la tabla de valores quedaron concentradas en el Anexo A.

\subsection{Diseño por etapas o ciudades}

El diseño no se hizo como un esquemático grande de una sola vez. Se trabajó por etapas, llamadas durante el desarrollo ``ciudades'', para separar las señales de milivoltios de las zonas de alimentación, protección y conectores. Esta decisión sigue el criterio de atenuación de ruido de separar fuentes de interferencia, retornos y señales sensibles para reducir acoplos capacitivos, inductivos y por impedancia común \cite{cardenas_ruido}; por eso ayuda a proteger rutas como la del SM-50, que entrega hasta 30 mV antes de amplificar.

Las ciudades usadas fueron: entrada y excitación del SM-50; acondicionamiento de torque con INA, ganancia y filtrado; entrada PT100 con fuente de corriente y líneas de sense; acondicionamiento de temperatura con offset, ganancia y filtrado; alimentación/protección desde B-Box; y salidas RJ45 hacia la B-Box. Esta forma de diseño permitió que cada ciudad tuviera una función clara: primero proteger y excitar el sensor, luego amplificar una señal pequeña, después filtrar, ajustar y finalmente entregar una señal robusta al sistema de adquisición.

\subsection{Selección de componentes y filtros}

Los valores de resistencias y capacitores se eligieron según su papel en la ruta de señal. En el PT100, $R_{\text{SET}}=2.49~\text{k}\Omega$ produce 0.5 mA con la referencia de 1.25 V; por eso se usó tolerancia baja. Las resistencias de entrada de 49.9 $\Omega$ y capacitores de 10 nF no buscan ganancia, sino limitar picos rápidos y atenuar ruido de alta frecuencia antes del INA sin volver lenta la medición.

El filtro principal se dejó como pasabajo RC de primer orden porque temperatura y torque son lentos frente al ruido eléctrico del banco. El corte de 159 Hz del PT100 no deforma la dinámica térmica, y el de 482 Hz del SM-50 conserva más banda para cambios de carga. Los 100 nF de desacoplo cerca de referencias, operacionales, INA y reguladores se usaron como reserva local de carga.

El trimmer multivuelta Bourns 3296W de 1 k$\Omega$ se incluyó como ajuste fino de laboratorio. No se usó para ``adivinar'' la ganancia, ya calculada por $R_G$, sino para corregir tolerancias, offset del puente, ruido del banco y dispersión de montaje. Al ser multivuelta permite ajustes pequeños y repetibles \cite{bourns3296}, de modo que RV1/RV2 dan margen de calibración sin rediseñar la PCB.

\section{Simulación en LTspice}

Las simulaciones se separaron por canal para depurar cada sensor sin mezclar errores. Primero se trabajó el PT100, luego el SM-50, y después se exportaron los barridos numéricos para regenerar las gráficas. Este flujo deja el resultado repetible si cambia un parámetro y mantiene el reporte centrado en el método seguido.

En el PT100, el barrido de 0 a 100 $^\circ$C confirmó que la resistencia sube de 100 $\Omega$ a 138.5 $\Omega$ y que la salida acondicionada aumenta de 2.33 V a 3.22 V. Esta salida absoluta incluye el punto de operación del circuito; lo importante es que el cambio de temperatura produce una variación clara, continua y dentro del rango de lectura.

En el SM-50, la simulación bipolar barrió de -50 lb a +50 lb. La tensión diferencial del puente llegó a $\pm30$ mV y, con $R_G=340~\Omega$, la salida del INA826 llegó a $\pm4.3888$ V, dejando alrededor de 0.61 V de margen antes de $\pm5$ V. Así se comprobó que la ganancia calculada era coherente con la interfaz de adquisición.

Además, los resultados se compararon con una investigación previa del banco LabCES con datos reales de sensores \cite{labces_prev}. En el PT100, las resistencias medidas a 0, 20, 50 y 100 $^\circ$C fueron aproximadamente 100.000, 107.793, 119.395 y 138.500 $\Omega$, muy cercanas al modelo usado en LTspice. En el SM-50, los datos previos mostraban offset y comportamiento no suficientemente limpio para tomarlos como calibración final; por eso se usaron como antecedente del problema. La calibración real debe hacerse con la PCB fabricada y cargas conocidas.

Para no saturar el cuerpo del reporte, las gráficas de simulación se colocaron en el Anexo B. En el texto principal se conservan únicamente los resultados que justifican las decisiones de diseño.

\section{Implementación en KiCad}

Después de validar los rangos en LTspice, el circuito se trasladó a KiCad. La PCB se organizó por bloques: entrada PT100, entrada SM-50, referencia/excitación, amplificación, filtrado, protección y salida hacia la B-Box. Esta separación ayudó a mantener trazabilidad entre cálculo, simulación y esquemático.

La selección de componentes siguió la función de cada etapa. El criterio común fue evitar componentes ``de relleno'': cada integrado, protección o pasivo debía ayudar a cumplir una restricción de la BoomBox, del sensor o de la señal medida. La interfaz con la BoomBox/B-Box se resolvió con conectores RJ45 8P8C blindados y cable FTP porque el equipo entrega entradas diferenciales, tierra y rieles de alimentación para sensores por el cable analógico \cite{imperix}; por eso la tarjeta separa alimentación, retorno y señales débiles desde el conector.

En el canal PT100, el REF3012 de 1.25 V se usó como referencia de la fuente de corriente, de modo que $I=V_{\text{ref}}/R_{\text{SET}}$ no dependiera de un divisor simple ni de variaciones directas del riel \cite{ref30}. El OPA2188 se eligió como operacional de precisión porque es zero-drift y presenta bajo offset, lo cual importa cuando la variación útil del RTD está en milivoltios \cite{opa2188}. El INA826 se mantuvo como amplificador diferencial porque mide señales pequeñas con rechazo de modo común y permite fijar la ganancia con una sola resistencia, $G=1+49.4~\text{k}\Omega/R_G$ \cite{ina826}.

En el canal SM-50, el TPS7A4901 genera la excitación de 10 V del puente desde el riel positivo disponible. Se escogió por ser un regulador de alto voltaje, bajo ruido y buena PSRR, adecuado para no inyectar ruido de alimentación en una señal de puente que antes de amplificar está en el orden de milivoltios \cite{tps7a49}, \cite{interface}. El regulador 78L05 se dejó como referencia local de 5 V para desacoplar bloques auxiliares del riel de la BoomBox; su salida fija, limitación de corriente y protección térmica lo hacen suficiente para una alimentación local sencilla \cite{lm78l}.

La protección también se justificó desde la forma real de uso. Como la BoomBox limita la alimentación de sensores a 100 mA, se agregó un PPTC 1812L050/30PR antes de distribuir rieles para tener protección resettable contra sobrecorriente \cite{littelfuse1812}. Las líneas hacia conectores se protegieron con TPD4E1U06 y SMF12CT1G: el primero aporta protección ESD de baja capacitancia para líneas de señal \cite{tpd4e1u06}, y el segundo funciona como arreglo TVS para transitorios en zonas expuestas \cite{smf12}. Finalmente, los trimmers multivuelta no se usaron para improvisar la ganancia, sino para compensar offset, ruido y dispersión de laboratorio; las redes RC limitan ancho de banda antes de la adquisición y los desacoplos de 100 nF/1 $\mu$F/10 $\mu$F dan reserva local de carga \cite{bourns3296}.

La parte mecánica también se justificó. Se usaron librerías locales de símbolos, footprints y modelos 3D; los integrados quedaron con encapsulados específicos; el TPS7A4901DGNT mantuvo su footprint DGN-8 con pad térmico; y los sensores se separaron en bornera de 3 pines para PT100 y de 4 pines para SM-50. La auditoría de footprints evitó mezclar modelos 3D con land patterns no verificados.

\subsection{Grosores y anchos de pista}

El stackup del proyecto se dejó como tarjeta de 1.6 mm con cobre externo de 35 $\mu$m, equivalente al cobre comercial típico de 1 oz. En la revisión del layout y del paquete Gerber actualizado se confirmaron pistas rutadas de 0.20, 0.25, 0.30, 0.40, 0.50 y 0.60 mm. Los anchos principales del diseño están entre 0.25 y 0.60 mm; el valor de 0.20 mm aparece solo en dos segmentos puntuales y el mayor ancho utilizado en fabricación es 0.60 mm. La documentación oficial de KiCad indica que estas reglas de diseño gobiernan el ruteo, la verificación DRC y los anchos disponibles durante el trazado \cite{kicad_pcbnew}.

La decisión no fue solo por espacio. El criterio eléctrico se revisó con el modelo IPC-2221 para pistas externas, usando 1 oz de cobre y 10 $^\circ$C de aumento térmico como caso conservador \cite{digikey_trace}. Esa corriente calculada no representa la corriente recibida por el circuito, sino un margen térmico de referencia frente al peor caso real: 0.5 mA en el PT100, 28.6 mA en el puente SM-50 y 100 mA como límite de alimentación de sensores de la B-Box. Por eso las pistas de 0.50 y 0.60 mm no se eligieron porque la corriente lo exigiera al límite, sino para reducir caída de tensión, mejorar robustez en conectores y separar físicamente potencia/retorno de las señales de milivoltios. La tabla completa de anchos y márgenes queda en el Anexo A.

Las vistas del diagrama funcional y de la PCB final se movieron al Anexo B para dejar el desarrollo principal más limpio.

\section{Validación y cumplimiento frente a la propuesta}

El primer objetivo se cubrió al aplicar fundamentos de PCB, ruteo por etapas, selección de anchos de pista, revisión de footprints y uso de KiCad. El segundo objetivo se atendió con simulaciones LTspice de los canales PT100 y SM-50, y con la comparación contra una investigación previa del banco que contenía datos reales de sensores. La verificación definitiva con la PCB final debe hacerse después de fabricar el prototipo.

El tercer objetivo se completó con el esquemático, layout, librerías locales, validaciones y paquete de fabricación. El cuarto objetivo, implementar y probar el prototipo en el sistema de medición, queda como cierre experimental pendiente porque la tarjeta aún no se ha fabricado ni ensamblado. En entregables, ya se cuenta con repositorio técnico, diseño completo, cálculos, simulaciones, validaciones ERC/DRC y paquete Gerber; quedan por completar el prototipo ensamblado, el manual final y la prueba integrada en el banco del LabCES.

La validación de cierre reportó 0 errores ERC, 0 advertencias ERC, 0 violaciones DRC, 0 pads desconectados y 0 errores de footprint. Además, el paquete de fabricación incluye las capas de cobre, máscara, pasta, serigrafía, contorno, descripción del trabajo, taladros y mapa de perforaciones. Esto no reemplaza una prueba eléctrica en laboratorio, pero sí confirma que el diseño digital quedó coherente y fabricable.

\section{Conclusiones}

El proyecto logró convertir una necesidad de medición del banco LabCES en una PCB trazable, simulada y preparada para fabricación. En el PT100, la corriente de 0.5 mA se escogió porque da sensibilidad suficiente sin castigar el sensor con autocalentamiento. En el SM-50, la excitación de 10 V y $R_G=340~\Omega$ permiten llevar una señal de $\pm30$ mV hasta $\pm4.39$ V, rango cómodo para la B-Box. Frente a la propuesta original, el diseño electrónico y la documentación técnica quedan cubiertos; la calibración real, el manual final y la prueba integrada deben cerrarse con el prototipo físico, usando resistencias patrón y cargas conocidas.

\section*{Anexo A: Cálculos y tablas de respaldo}

\subsection*{A.1 Canal PT100}

El modelo usado para el PT100 en el rango positivo fue
\begin{equation}
R(T)=R_0(1+AT+BT^2),
\end{equation}
donde $R_0=100~\Omega$, $A=3.9083\times10^{-3}$ y $B=-5.775\times10^{-7}$ \cite{bipm}. Con esto, $R(100^\circ\text{C})\approx138.5~\Omega$.

La corriente de excitación se calculó a partir de la referencia y la resistencia de ajuste:
\begin{equation}
I_{\text{PT100}}=\frac{1.25~\text{V}}{2.49~\text{k}\Omega}=0.502~\text{mA}.
\end{equation}
El span crudo entre 0 y 100 $^\circ$C queda como
\begin{equation}
\Delta V_{\text{PT100}}=0.5~\text{mA}(138.5-100)\Omega=19.25~\text{mV}.
\end{equation}
Con $R_G=1~\text{k}\Omega$ en el INA826, $G=50.40$ V/V, de modo que el span amplificado es cercano a 0.970 V. Para una B-Box de 16 bits sobre 10 V de span, el LSB ideal es 152.6 $\mu$V, equivalente a una resolución eléctrica estimada de 0.0157 $^\circ$C/LSB. El autocalentamiento también queda bajo: con $\Delta T=I^2R/E$ y $E=2.5$ mW/$^\circ$C, la potencia máxima en el PT100 es 34.6 $\mu$W y el error térmico calculado es cercano a 0.014 $^\circ$C \cite{ti_rtd}.

\subsection*{A.2 Canal SM-50}

La salida de escala completa del puente, usando 10 V de excitación, fue
\begin{equation}
V_{\text{diff,FS}}=3~\text{mV/V}\cdot10~\text{V}=30~\text{mV}.
\end{equation}
La corriente y potencia del puente se estimaron como
\begin{equation}
I_{\text{puente}}=\frac{10~\text{V}}{350~\Omega}=28.6~\text{mA},
\end{equation}
\begin{equation}
P_{\text{puente}}=\frac{(10~\text{V})^2}{350~\Omega}=286~\text{mW}.
\end{equation}
Para llevar 30 mV a aproximadamente 4.39 V se necesita una ganancia de 146.3 V/V. Con el INA826:
\begin{equation}
G=1+\frac{49.4~\text{k}\Omega}{R_G},
\end{equation}
y usando $R_G=340~\Omega$, se obtiene $G=146.29$ V/V.

\subsection*{A.3 Filtros}

Los filtros de salida se calcularon como pasabajos RC de primer orden:
\begin{equation}
f_c=\frac{1}{2\pi RC}.
\end{equation}
Para PT100, $R=10~\text{k}\Omega$ y $C=100~\text{nF}$ dan $f_c\approx159$ Hz. Para SM-50, $R=10~\text{k}\Omega$ y $C=33~\text{nF}$ dan $f_c\approx482$ Hz.

\begin{table}[H]
\caption{Resumen de valores principales usados en el diseño}
\label{tab:valores}
\centering
\scriptsize
\begin{tabular}{@{}p{0.18\linewidth} p{0.31\linewidth} p{0.37\linewidth}@{}}
\toprule
Bloque & Valor o resultado & Justificación \\
\midrule
B-Box & $\pm5$ V, 16 bits & Define margen y resolución de salida \cite{imperix}. \\
PT100 & $R(100^\circ\text{C})\approx138.5~\Omega$ & Rango térmico de referencia \cite{bipm}. \\
PT100 & $I_{\text{exc}}=0.502$ mA & Señal útil con bajo autocalentamiento \cite{ti_rtd}. \\
PT100 & $G=50.40$ V/V; span 0.970 V & Compatible con adquisición sin saturar. \\
SM-50 & 10 V de excitación; 30 mV FS & Dato nominal del sensor \cite{interface}. \\
SM-50 & $G=146.29$ V/V; salida $\pm4.39$ V & Escala la señal al rango de la B-Box. \\
Filtros & 159 Hz PT100; 482 Hz SM-50 & Atenúa ruido sin eliminar dinámica útil \cite{adi_paths}. \\
\bottomrule
\end{tabular}
\end{table}

\subsection*{A.4 Anchos de pista de la PCB}

Para revisar el margen térmico de las pistas se usó la relación IPC-2221 para pistas externas:
\begin{equation}
I=k(\Delta T)^bA^c,
\end{equation}
donde para capas externas $k=0.048$, $b=0.44$ y $c=0.725$ \cite{digikey_trace}, \cite{cirexx_trace}. El cálculo se hizo con cobre de 1 oz, $\Delta T=10^\circ$C y pistas externas. Estos resultados son estimados, pero sirven para demostrar que el diseño no está cerca de un límite térmico.

\begin{table}[H]
\caption{Anchos de pista confirmados en fabricación y margen frente a 100 mA}
\label{tab:pistas}
\centering
\tiny
\setlength{\tabcolsep}{2pt}
\begin{tabular}{@{}p{0.14\linewidth} p{0.34\linewidth} p{0.18\linewidth} p{0.20\linewidth}@{}}
\toprule
Ancho & Uso en la PCB & Margen vs. 100 mA & Caída, 100 mA/50 mm \\
\midrule
0.20 mm & Segmentos puntuales confirmados & 7.4$\times$ & 12.31 mV \\
0.25 mm & Señales analógicas; ancho dominante & 8.8$\times$ & 9.85 mV \\
0.30 mm & Ajustes y salidas locales & 10.0$\times$ & 8.21 mV \\
0.40 mm & Referencias y tramos intermedios & 12.3$\times$ & 6.16 mV \\
0.50 mm & Rieles protegidos y conectores & 14.5$\times$ & 4.93 mV \\
0.60 mm & Alimentación, retorno y pantallas con margen extra & 16.5$\times$ & 4.10 mV \\
\bottomrule
\end{tabular}
\end{table}

\begin{figure*}[t]
\centering
{\Large\scshape Anexo B: Figuras de simulación y KiCad\par}
\vspace{4pt}
\begin{minipage}{0.49\linewidth}
\centering

\end{minipage}
\hfill
\begin{minipage}{0.49\linewidth}
\centering

\end{minipage}
\caption{Resultados de simulación usados para validar los rangos de salida. Izquierda: respuesta del canal PT100. Derecha: salida bipolar del SM-50 dentro de $\pm5$ V.}
\label{fig:sim}
\end{figure*}

\begin{figure*}[t]
\centering

\caption{Esquemático de simulación en LTspice para el canal PT100.}
\label{fig:ltspice_sch}
\end{figure*}

\begin{figure*}[t]
\centering

\caption{Esquemático de simulación en LTspice para el canal SM-50.}
\label{fig:ltspice_sm50_sch}
\end{figure*}

\begin{figure*}[t]
\centering

\caption{Esquemático principal de la tarjeta de acondicionamiento implementado en KiCad.}
\label{fig:kicad_sch}
\end{figure*}

\begin{figure*}[t]
\centering

\caption{Diagrama funcional del acondicionamiento, con los valores finales usados para PT100, SM-50 e interfaz B-Box.}
\label{fig:bloques}
\end{figure*}

\begin{figure*}[t]
\centering

\caption{Vista 3D de la PCB final en KiCad. La revisión permite verificar conectores, encapsulados y distribución física antes de fabricar.}
\label{fig:pcb}
\end{figure*}

\clearpage
\onecolumn
\begin{multicols*}{2}
\begin{thebibliography}{00}
\setlength{\itemsep}{0pt}
\setlength{\parsep}{0pt}
\bibitem{adi_paths} Analog Devices, ``Overview of Sensor Signal Paths,'' technical article, May 2010. [En línea]. Disponible: \url{https://www.analog.com/en/resources/technical-articles/overview-of-sensor-signal-paths.html}
\bibitem{imperix} imperix, ``User Manual BoomBox,'' entradas analógicas y alimentación de sensores. [En línea]. Disponible: \url{https://imperix.com/wp-content/uploads/2018/06/User-Manual-BoomBox.pdf}
\bibitem{bipm} BIPM, ``Guide on Secondary Thermometry: Industrial Platinum Resistance Thermometers,'' Consultative Committee for Thermometry, 2021. [En línea]. Disponible: \url{https://www.bipm.org/documents/20126/41773843/BIPM_CCT_Guide_to_IPRTs.pdf}
\bibitem{ref30} Texas Instruments, ``REF30E and REF30 Low Current Voltage Reference in SOT-23-3,'' hoja de datos. [En línea]. Disponible: \url{https://www.ti.com/lit/gpn/REF30E}
\bibitem{interface} Interface Force Measurement Solutions, ``Model SM S-Type Load Cell,'' hoja de datos. [En línea]. Disponible: \url{https://www.scienspec.com.tw/userfiles/files/SM.pdf}
\bibitem{ina826} Texas Instruments, ``INA826 Precision, 200-uA Supply Current, 3-V to 36-V Instrumentation Amplifier,'' hoja de datos. [En línea]. Disponible: \url{https://www.ti.com/lit/ds/symlink/ina826.pdf}
\bibitem{sloa034} Texas Instruments, ``Signal Conditioning Wheatstone Resistive Bridge Sensors,'' SLOA034. [En línea]. Disponible: \url{https://www.ti.com/lit/pdf/sloa034}
\bibitem{sboa247} Texas Instruments, ``Single-Supply Strain Gauge Bridge Amplifier Circuit,'' SBOA247A. [En línea]. Disponible: \url{https://www.ti.com/lit/pdf/sboa247}
\bibitem{an43} Analog Devices, ``AN-43: Bridge Circuits.'' [En línea]. Disponible: \url{https://www.analog.com/en/resources/app-notes/an-43f.html}
\bibitem{an96} Analog Devices, ``AN-96: Delta Sigma ADC Bridge Measurement Techniques.'' [En línea]. Disponible: \url{https://www.analog.com/en/resources/app-notes/an-96fa.html}
\bibitem{adi_rtd} Analog Devices, ``How to Select and Design the Best RTD Temperature Sensing System,'' Analog Dialogue. [En línea]. Disponible: \url{https://www.analog.com/en/resources/analog-dialogue/articles/how-to-select-and-design-the-best-rtd-temperature-sensing-system.html}
\bibitem{ti_rtd} Texas Instruments, ``A Basic Guide to RTD Measurements,'' SBAA275A, application note, 2023. [En línea]. Disponible: \url{https://www.ti.com/lit/pdf/sbaa275}
\bibitem{cardenas_ruido} R. Cárdenas Dobson, ``Atenuación de ruidos en circuitos electrónicos,'' apuntes del curso de proyecto, Universidad de Magallanes.
\bibitem{bourns3296} Bourns, ``3296 -- 3/8 Inch Square Trimpot Trimming Potentiometer,'' hoja de datos. [En línea]. Disponible: \url{https://www.bourns.com/docs/product-datasheets/3296.pdf}
\bibitem{labces_prev} LabCES, ``Caracterización de sensores y datos experimentales previos del banco de motor de inducción,'' documentación interna usada como antecedente experimental previo, 2026.
\bibitem{opa2188} Texas Instruments, ``OPA2188 Low-Noise, 36-V, Zero-Drift Operational Amplifiers,'' hoja de datos. [En línea]. Disponible: \url{https://www.ti.com/lit/gpn/OPA2188}
\bibitem{tps7a49} Texas Instruments, ``TPS7A49 36-V, 150-mA, Ultralow-Noise Positive Linear Regulator,'' hoja de datos. [En línea]. Disponible: \url{https://www.ti.com/lit/gpn/TPS7A49}
\bibitem{lm78l} Texas Instruments, ``LM78L 100-mA Fixed Output Linear Regulator,'' hoja de datos. [En línea]. Disponible: \url{https://www.ti.com/lit/ds/symlink/lm78l.pdf}
\bibitem{littelfuse1812} Littelfuse, ``1812L Series Surface Mount Resettable PPTC,'' hoja de datos. [En línea]. Disponible: \url{https://www.littelfuse.com/assetdocs/resettable-ptcs-1812l-datasheet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}
\bibitem{tpd4e1u06} Texas Instruments, ``TPD4E1U06 Quad-Channel High-Speed ESD Protection Device,'' hoja de datos. [En línea]. Disponible: \url{https://www.ti.com/lit/gpn/TPD4E1U06}
\bibitem{smf12} onsemi, ``SMF05CT1G, SMF12CT1G, SMF15CT1G, SMF24CT1G ESD Protection Diode Array,'' hoja de datos. [En línea]. Disponible: \url{https://www.onsemi.com/download/data-sheet/pdf/smf05c-d.pdf}
\bibitem{kicad_pcbnew} KiCad, ``PCB Editor Documentation: Board Setup, Design Rules, Net Classes and Track Width,'' documentación oficial, versión 8.0. [En línea]. Disponible: \url{https://docs.kicad.org/8.0/en/pcbnew/pcbnew.html}
\bibitem{digikey_trace} DigiKey, ``PCB Trace Width Conversion Calculator,'' herramienta técnica basada en IPC-2221. [En línea]. Disponible: \url{https://www.digikey.com/en/resources/conversion-calculators/conversion-calculator-pcb-trace-width}
\bibitem{cirexx_trace} Cirexx International, ``Trace Width Calculator,'' herramienta técnica basada en IPC-2221. [En línea]. Disponible: \url{https://www.cirexx.com/trace-width-calculator/}
\end{thebibliography}
\end{multicols*}

\end{document}

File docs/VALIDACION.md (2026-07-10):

# Validación final del diseño

Fecha de cierre de validación: 2026-06-26.

## Resumen

El proyecto KiCad principal fue validado después de actualizar el esquemático, el PCB, las vistas documentales y el paquete Gerber con taladros.

| Revisión | Resultado |
| --- | --- |
| ERC KiCad | 0 errores, 0 advertencias |
| DRC KiCad | 0 violaciones |
| Pads desconectados | 0 |
| Errores de footprint | 0 |
| Paridad esquemático-PCB | 0 problemas |
| ZIP Gerber | Incluye cobre, máscara, pasta, serigrafía, contorno, `.gbrjob`, `.drl` y mapa de taladros |

## Reportes

- `docs/validacion/erc_final_20260626.rpt`
- `docs/validacion/drc_final_20260626.rpt`

## Fabricación

El ZIP listo para subir al fabricante está en:

`docs/fabricacion/PCB_PT100_SM50_GERBERS_CON_DRILL.zip`

También se dejó una copia actualizada en:

`C:\Users\kenne\Downloads\PCB_PT100_SM50_GERBERS_CON_DRILL.zip`

## Notas de serigrafía

Se mantuvieron las referencias visibles. Las advertencias finales estaban relacionadas con texto de serigrafía sobre cobre/máscara o superposiciones entre referencias. Se corrigieron moviendo referencias y usando altura mínima de 0.8 mm, que coincide con la regla configurada en KiCad para este proyecto.

## Simulaciones documentadas

Los datos finales usados para las gráficas corregidas están en `docs/simulacion/`:

- `pt100_sweep_ng_20260625.csv`
- `sm50_sweep_bipolar_ng_20260629.csv`
- `resumen_numerico_ng_20260625.json`

Las gráficas generadas están en `docs/figuras/` y documentan el SM-50 con salida bipolar nominal de +/-4.39 V, dentro del rango +/-5 V de la B-Box.

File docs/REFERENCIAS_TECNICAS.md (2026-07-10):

# Referencias técnicas y componentes

Este documento resume las fuentes técnicas conservadas en el proyecto y las verificaciones principales de componentes.

## Fuentes del proyecto

| Ruta | Uso |
| --- | --- |
| `PCB_PT100_SM50/PCB_PT100_SM50.kicad_sch` | Esquemático KiCad principal. |
| `PCB_PT100_SM50/PCB_PT100_SM50.kicad_pcb` | PCB final. |
| `PCB_PT100_SM50/symbols/` | Símbolos locales usados por el esquemático. |
| `PCB_PT100_SM50/footprints/` | Footprints locales y ajustados. |
| `PCB_PT100_SM50/3d/` | Modelos 3D usados en KiCad. |
| `ProyectoPCB_LTspice_PT100_SM50/` | Simulaciones LTspice. |
| `PCB_PT100_SM50/ltspice_models/` | Modelos SPICE copiados al proyecto KiCad. |
| `docs/simulacion/calculos_PT100_SM50_VALORES_ACTUALES_v2.csv` | Cálculos finales de PT100, SM-50 e interfaz B-Box. |
| `docs/referencias/referencias_completas_proyecto_PCB.txt` | Referencias finales, teóricas, de PCB y de trazabilidad usadas en la memoria vigente. |
| `docs/bitacora/bitacora_PCB_actualizada_27_06_2026.pdf` | Bitácora cronológica del proyecto desde el 11/03/2026 hasta el 27/06/2026. |
| `docs/figuras/diagrama_bloques_valores_actuales.png` | Diagrama de bloques con valores actuales de ambos canales. |

## Componentes revisados

| Bloque | Componentes / modelos | Resultado |
| --- | --- | --- |
| Entrada PT100 | Bornera METZ AST0250304, TVS/ESD, resistencias de excitación | Footprint ajustado contra datasheet y validado por DRC. |
| Entrada SM-50 | Bornera METZ AST0250404, protección y excitación | Footprint aplicado con modelo 3D verde y DRC limpio. |
| Amplificación | INA826AIDR, OPA2188AIDR | Footprints SOIC-8 compatibles con BOM. |
| Regulación/referencia | TPS7A4901DGNT, REF3012, reguladores auxiliares | Footprint PowerPAD ajustado con pad térmico correcto. |
| Protección | SMF12CT1G, PPTC 1812 | Footprints y serigrafía revisados. |
| Interfaz | RJ45 / B-Box | Modelo 3D y conectividad revisados. |

## Verificación de footprints descargados

El resumen completo está en:

`docs/referencias/RESUMEN_VERIFICACION_FOOTPRINTS_DESCARGADOS_20260625.md`

Los paquetes crudos descargados de proveedores no se versionan porque ocupan espacio y contienen formatos que no se usan directamente en KiCad. En el repositorio se conservan las librerías finales necesarias para abrir y fabricar el proyecto.

## Norma práctica usada para referencias

Para serigrafía se mantuvo la regla del proyecto KiCad:

- Altura mínima de texto: 0.8 mm.
- Espesor mínimo usado en referencias pequeñas: 0.1 mm.
- Las referencias se movieron fuera de pads, máscara y contornos de componentes.

Esto evita advertencias DRC y mantiene legibilidad razonable en fabricación.

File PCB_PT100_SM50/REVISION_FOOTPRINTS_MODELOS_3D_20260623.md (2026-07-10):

# Revisión de footprints y modelos 3D - 2026-06-23

Proyecto revisado: `C:\Users\kenne\Documents\KiCad\PCB_PT100_SM50`

## Cambios aplicados

- `ProyectoPCB:2250066-1`
  - Huella corregida contra el dibujo oficial Bel Fuse / TRP `C-2250066`.
  - Se ajustó la fila de pines 2/4/6/8 para que no quede espejada respecto al layout sugerido.
  - Se agregaron los 2 taladros NPTH de 3.2 mm para postes plásticos.
  - Se corrigieron taladros de señal a 0.89 mm y blindaje a 1.57 mm.
  - Modelo 3D: `${KIPRJMOD}/3d/2250066-1.stp`, offset `Z=5.75`, escala `(1 1 1)`.
  - Nota: el STEP del ZIP local del RJ45 parece renderizar solo subpartes/elementos metálicos, no un cuerpo completo claramente visible del jack.

- `ProyectoPCB:SMF12CT1G_SC88_SOT363`
  - Se agregó modelo 3D local `${KIPRJMOD}/3d/SOT-363-6_2P2X1P35_ONS.step`.

- `ProyectoPCB_Footprints:PPTC_1812L050_30PR_1812`
  - Se agregó modelo 3D 1812 global de KiCad a la librería y a las 4 instancias colocadas.

- `ProyectoPCB_Footprints:Bourns_3296W_1_102LF`
  - Se corrigió la huella custom al orden físico `1-3-2` indicado por Bourns para 3296W-1.

- `ProyectoPCB_Footprints:REF3012AIDBZR_SOT-23-3`
  - Se agregó modelo 3D local `${KIPRJMOD}/3d/DBZ0003A.stp`.

- `ProyectoPCB_Footprints:TPS7A4901DGNT_HVSSOP-8-EP`
  - Se agregó modelo 3D local `${KIPRJMOD}/3d/DGN0008G.stp`.

- Terminales METZ
  - Se agregaron huellas locales:
    - `TerminalBlock_METZ_AST0250304_1x03_P5.00mm`
    - `TerminalBlock_METZ_AST0250404_1x04_P5.00mm`

## Respaldos creados

- `backup_footprints_20260623_212949`
- `PCB_PT100_SM50_before_board_sync_*.kicad_pcb`

## Validación

- KiCad CLI detectado: `9.0.7`.
- El PCB abre con `kicad-cli pcb drc`.
- DRC después de la sincronización RJ45/modelos:
  - 27 violaciones.
  - 124 ítems sin conectar.

## Pendientes importantes

- El RJ45 `J_BBOX_SM50` ahora usa los postes reales del fabricante. Uno de esos NPTH queda demasiado cerca del mounting hole `H2`. Hay que mover `H2`, mover ligeramente el RJ45, o cambiar la estrategia mecánica del mounting hole.
- Al corregir el RJ45, los pines 2/4/6/8 quedaron en la posición real del fabricante. Revisa o vuelve a rutear las conexiones de ambos RJ45 antes de fabricar.
- El esquemático aún tiene `TRIM_PT100` y `TRIM_SM50` apuntando al footprint stock de KiCad. La huella custom corregida ya está disponible como `ProyectoPCB_Footprints:Bourns_3296W_1_102LF`.
- Los conectores de terminal colocados siguen siendo Phoenix 5.00 mm. Las huellas METZ correctas ya están agregadas, pero no se cambiaron las instancias colocadas para no alterar la mecánica sin revisar.

## Fuentes usadas

- Bel Fuse / TRP drawing `C-2250066`, `dr-mag-2250066.pdf`.
- Bourns 3296 datasheet: `https://www.bourns.com/docs/product-datasheets/3296.pdf`.
- Modelos 3D STEP desde los ZIP locales de `C:\Users\kenne\Downloads\Footprints`.

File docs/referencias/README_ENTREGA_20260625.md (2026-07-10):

# Entrega PCB PT100 + SM50

Fecha de preparación: 2026-06-25

## Estado general

- Proyecto KiCad corregido y validado.
- ERC final: 0 errores, 0 warnings.
- DRC final: 0 violaciones.
- Pads sin conectar: 0.
- Paridad esquemático-PCB: 0 issues.
- Conectores RJ45 BBOX corregidos: pines 3, 5 y 6 en GND para PT100 y SM50.
- Footprints críticos actualizados contra los ZIPs/modelos revisados: `J_PT100_1` = AST0250304, `J_SM50` = AST0250404, `U3` = TPS7A4901DGNT DGN/HVSSOP-8 PowerPAD.
- La alimentación -15 V queda usada como alimentación negativa/protegida de opamps/INA y BBOX, no como salida de sensor.

## Para fabricar PCB

Archivo recomendado para subir directo al fabricante:

`fabricacion/PCB_PT100_SM50_GERBERS_CON_DRILL.zip`

Ese ZIP incluye las capas Gerber y el archivo de taladros Excellon `PCB_PT100_SM50.drl` en la raíz del ZIP, para evitar el error "There is no drill layer in the file".

También se puede enviar al fabricante el contenido de:

`fabricacion/`

Incluye:

- `gerbers/`: capas Gerber exportadas desde KiCad.
- `drill/`: archivo Excellon de taladros y mapa PDF.
- `ensamble_visual/`: Gerber/PDF/SVG de referencia visual con `F.Fab`, `F.SilkS` y borde de placa para ver mejor las etiquetas de componentes. Usar como apoyo de revisión/ensamble, no como reemplazo de los Gerbers de fabricación.

## Para ensamble

Usar:

- `ensamble/PCB_PT100_SM50_BOM.csv`
- `ensamble/PCB_PT100_SM50_BOM_unitaria.csv`
- `ensamble/PCB_PT100_SM50_pos.csv`
- `ensamble/99915123_DigiKey_original.csv`
- `ensamble/REVISION_BOM_FOOTPRINTS_20260625.csv`

Nota: H1-H4 y el logo estan marcados como `board_only` y excluidos de BOM/POS.

Referencias cortas: se normalizaron las referencias largas de resistencias/capacitores/trimmers a designadores compactos tipo letra + número. Cambios principales: `R_LIM_PT100` -> `R9`, `R_LIM_SM50` -> `R11`, `R_ISO_PT100` -> `R12`, `R_ISO_SM50` -> `R13`, `RSET_PT100` -> `R14`, `C_OUT_SM50` -> `C27`, `C_OUT_PT100` -> `C28`, `TRIM_SM50` -> `RV1`, `TRIM_PT100` -> `RV2`. En zonas densas el texto de referencia en PCB se dejó en 0.8 mm, respetando el mínimo DRC del proyecto.

Referencias activas: se dejaron visibles las referencias reales del PCB en `F.SilkS`/`F.Fab` y se reubicaron las que tocaban cobre o serigrafía. Solo permanecen ocultos los placeholders de gráficos/logos (`REF**`, `G***`) y las referencias de potencia en el esquemático (`#PWR`, `#FLG`), por convención de KiCad.

## Validación

Archivos principales:

- `validacion/erc_final_conjunto_20260625.rpt`
- `validacion/drc_final_conjunto_20260625.rpt`
- `validacion/netlist_final_conjunto_20260625.xml`
- `validacion/PCB_PT100_SM50_esquematico_20260625.pdf`
- `validacion/pcb_layers_pdf_export/PCB_PT100_SM50.pdf`
- `validacion/PCB_PT100_SM50_3D_20260625.step`
- `validacion/RESUMEN_VERIFICACION_FOOTPRINTS_DESCARGADOS_20260625.md`

## Simulación

Las corridas se hicieron con el motor `ngspice.dll` incluido en KiCad 9.0, no con LTspice.

Resultados principales:

- PT100, 130 C: `VOUT_PT100_BBOX = 4.369544 V`.
- SM50, escala completa bipolar, RG=340 ohm: `VOUT_SM50_BBOX = +/-4.39 V`.
- Simulación conjunta idealizada: el SM-50 se documenta con salida bipolar nominal dentro del rango +/-5 V.

Archivos:

- `simulacion/sim_kicad_ngspice_pt100_sweep_ng_20260625.csv`
- `docs/simulacion/sm50_sweep_bipolar_ng_20260629.csv`
- `simulacion/sim_kicad_ngspice_numeric_summary_ng_20260625.json`
- `simulacion/sim_kicad_ngspice_conjunto_ideal_pos_ng_20260625.log`

Nota: el netlist SPICE exportado directamente desde el esquemático KiCad aún contiene placeholders de símbolos sin modelo SPICE asignado. Por eso las simulaciones numéricas finales usan bancos idealizados compatibles con ngspice de KiCad.

## Fuentes KiCad

`fuentes_kicad/` contiene el proyecto KiCad corregido y las librerías locales necesarias para reabrirlo:

- `.kicad_pro`
- `.kicad_sch`
- `.kicad_pcb`
- tablas de librerías
- footprints, símbolos y modelos 3D locales

## GitHub

Al momento de preparar esta entrega, el repositorio local no tiene remoto configurado (`git remote -v` no muestra `origin`). Por eso no se pudo confirmar ni hacer push a GitHub desde esta copia.

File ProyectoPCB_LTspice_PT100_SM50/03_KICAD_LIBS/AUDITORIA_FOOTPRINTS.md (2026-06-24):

# Auditoria de footprints y modelos 3D

Objetivo: evitar que un modelo 3D de DigiKey/Ultra Librarian se confunda con un
footprint validado para fabricacion. Los ZIPs revisados contenian modelos STEP/STP;
la orden de compra agrego MPNs que no estaban en esos ZIPs.

## Verificado con fuente de fabricante

| Parte | Resultado |
| --- | --- |
| `INA826AIDR` | Simbolo `INA826_SOIC8` con pinout de TI. Footprint especifico `SOIC-8_3.9x4.9mm_P1.27mm_INA826AIDR` enlazado a `INA826AIDR_TI_SOIC8_D0008A.stp`. |
| `OPA2188AIDR` | Simbolo `OPA2188_SOIC8` con pinout de TI. Footprint especifico `SOIC-8_3.9x4.9mm_P1.27mm_OPA2188AIDR` enlazado a `OPA2188AIDR_TI_SOIC8_D0008A.stp`. |
| `REF3012AIDBZR` | Simbolo `REF30E_SOT23` y footprint `SOT-23-3` con modelo `REF3012AIDBZR_TI_SOT23_DBZ0003A.stp`. Pinout: 1=IN, 2=OUT, 3=GND. |
| `TPD4E1U06DBVR` | Simbolo y footprint especificos. El land pattern usa 6 pads de 1.1 mm x 0.6 mm, pitch 0.95 mm y separacion de filas 2.6 mm, segun TI DBV0006A. |
| `TPS7A4901DGNT` | Simbolo y footprint especificos. El land pattern usa pads 1.4 mm x 0.45 mm, pitch 0.65 mm, separacion de filas 4.4 mm y PowerPAD 1.57 mm x 1.89 mm, segun TI DGN0008G. |
| `C2012X7R1H105K085AC` | TDK confirma serie C2012 / EIA 0805, 2.00 mm x 1.25 mm x 0.85 mm. Se creo footprint especifico `C_0805_2012Metric_TDK_C2012X7R1H105K085AC` con su STEP local. |
| `2250066-1` | Bel/TRP confirma MagJack 10/100 tab-up. Se creo `RJ45_BelFuse_2250066-1` con 8x taladro 0.89 mm, 2x shield 1.57 mm y 2x postes NPTH 3.2 mm segun drawing C-2250066. STEP enlazado; revisar ajuste visual 3D en KiCad. |
| `1812L050/30PR` | Littelfuse 1812L050/30PR confirmado en datasheet 1812L. Se creo footprint `Fuse_1812_4532Metric_Littelfuse_1812L050-30PR`. |
| `3296W-1-102LF` | Bourns 3296W top-adjust confirmado en datasheet. Se creo `Potentiometer_Bourns_3296W_1x03_P2.54mm` con orden fisico de pads 1-3-2. |

## Consistente mecanicamente, pendiente de fuente primaria completa o STEP exacto

| Parte | Estado |
| --- | --- |
| `AST0250304` / `AST0250404` | La orden de compra indica borneras METZ de 5.00 mm. Se crearon footprints `TerminalBlock_METZ_AST0250304_1x03_P5.00mm` y `TerminalBlock_METZ_AST0250404_1x04_P5.00mm`; falta STEP/drawing local exacto. |
| `08055C104K4T2A` | El STEP se identifica como `CAP_0805_AVX`. Se creo footprint especifico `C_0805_2012Metric_AVX_08055C104K4T2A`. Pendiente confirmar land pattern oficial AVX/Kyocera si se va a liberar a fabricacion. |
| `08055C333KAT2A` | El STEP se identifica como `CAP_X7R_0805_AVX`. No es el MPN comprado para 33 nF; la compra trae `KGM21NR71H333KT`. |
| `08055C103K4T2A` | Agregado como simbolo `C_08055C103K4T2A` con footprint 0805 generico. Falta STEP exacto local. |
| `KGM21NR71H333KT` | Agregado como simbolo `C_KGM21NR71H333KT` con footprint 0805 generico. Falta STEP exacto local. |
| `GRM21BR61E106KA73K` | Agregado como simbolo `C_GRM21BR61E106KA73K` con footprint 0805 generico. Falta STEP exacto local. |
| `RT0805BRD07...` | El STEP se identifica como `RC0805N_YAG`. Se separo en footprint especifico `R_0805_2012Metric_Yageo_RT0805BRD` para no usar ese modelo en resistencias TE/CPF. |
| `CPF0805...` | Agregado como simbolo `R_CPF0805` con footprint 0805 generico. Falta STEP exacto local. |
| `SMF12CT1G` | El STEP se identifica como `SOT-363-6_2P2X1P35_ONS`. Se conserva footprint mecanico `SOT-363-6_SMF12CT1G`, pero no hay simbolo funcional porque falta confirmar pinout desde datasheet oficial. |

## Correcciones realizadas

- Corregi `2250066-1`: en la compra es Bel Fuse/TRP, no TE. El STEP local ahora se llama `2250066-1_BelFuse.stp`.
- Cree footprint y simbolo para `J_2250066_1_MAGJACK` usando el drawing oficial de Bel/TRP.
- Cambie los conectores PT100/SM50/alimentacion de 5.08 mm generico a METZ 5.00 mm cuando aplican a la compra.
- Quite el modelo 3D del footprint generico `SOIC-8_3.9x4.9mm_P1.27mm`; ahora no muestra por error un INA826 cuando el simbolo sea OPA2188, OPA188 o INA828.
- Cree footprints especificos para `INA826AIDR` y `OPA2188AIDR`, cada uno con su STEP.
- Quite el modelo 3D del footprint generico `C_0805_2012Metric`; ahora los modelos 3D de capacitor estan en footprints especificos por MPN.
- Quite el modelo 3D del footprint generico `R_0805_2012Metric`; el STEP Yageo quedo en `R_0805_2012Metric_Yageo_RT0805BRD`.
- Marque `TPS7A4901DGNT` como parte distinta del bloque LTspice `TPS7A4701_10V`. No son el mismo regulador.

## Pendientes antes de fabricar

- Abrir en KiCad el visor 3D del `RJ45_BelFuse_2250066-1` y ajustar offset/rotacion del STEP si no calza con el footprint.
- Confirmar datasheet/pinout de `SMF12CT1G` antes de conectarlo electricamente.
- Conseguir STEP exacto si quieres visual 3D para `AST0250304`, `AST0250404`, `1812L050/30PR`, `3296W-1-102LF`, `CPF0805...`, `08055C103K4T2A`, `KGM21NR71H333KT` y `GRM21BR61E106KA73K`.
- Si se cambia el regulador SM50 desde `TPS7A4701` a `TPS7A4901DGNT`, hay que actualizar tambien el esquematico electrico, no solo el footprint.

## Fuentes primarias usadas

- TI INA826: https://www.ti.com/lit/ds/symlink/ina826.pdf
- TI OPA2188: https://www.ti.com/lit/ds/symlink/opa2188.pdf
- TI REF30/REF30E: https://www.ti.com/lit/ds/symlink/ref30e.pdf
- TI TPD4E1U06: https://www.ti.com/lit/ds/symlink/tpd4e1u06.pdf
- TI TPS7A49/TPS7A4901: https://www.ti.com/lit/ds/symlink/tps7a49.pdf
- TDK C2012X7R1H105K085AC: https://product.tdk.com/en/search/capacitor/ceramic/mlcc/info?part_no=C2012X7R1H105K085AC
- Bel Fuse 2250066-1: https://www.belfuse.com/products/ethernet/magjacks-icms/2250066-1
- Bel drawing C-2250066: https://www.belfuse.com/media/drawings/products/magjack%20ICMs/dr-mag-2250066.pdf
- Bel Industrial Ethernet MagJack ICMs: https://www.belfuse.com/media/datasheets/products/magjack%20ICMs/ds-mag-industrial-ethernet-magjack-icms.pdf
- Littelfuse 1812L: https://www.littelfuse.com/~/media/electronics/datasheets/resettable_ptcs/littelfuse_ptc_1812l_datasheet.pdf.pdf
- Bourns 3296: https://www.bourns.com/docs/Product-Datasheets/3296.pdf

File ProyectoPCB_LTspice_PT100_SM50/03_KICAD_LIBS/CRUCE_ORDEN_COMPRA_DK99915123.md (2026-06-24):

# Cruce orden DigiKey 99915123 contra libreria KiCad

Fuente local: `C:\Users\kenne\Downloads\SALESORDER_EMAIL99915123.pdf`.

| Item | MPN comprado | Simbolo KiCad | Footprint | 3D local | Estado |
| --- | --- | --- | --- | --- | --- |
| INA826AIDR | INA826AIDR | `INA826_SOIC8` | `SOIC-8_3.9x4.9mm_P1.27mm_INA826AIDR` | si | Listo. |
| OPA2188AIDR | OPA2188AIDR | `OPA2188_SOIC8` | `SOIC-8_3.9x4.9mm_P1.27mm_OPA2188AIDR` | si | Listo. |
| REF3012AIDBZR | REF3012AIDBZR | `REF30E_SOT23` | `SOT-23-3` | si | Listo. |
| TPS7A4901DGNT | TPS7A4901DGNT | `TPS7A4901DGNT` | `HVSSOP-8-1EP_DGN0008G_TPS7A4901DGNT` | si | Listo; no reemplaza el bloque LTspice TPS7A4701 sin redisenar. |
| TPD4E1U06DBVR | TPD4E1U06DBVR | `TPD4E1U06DBVR` | `SOT-23-6_DBV0006A_TPD4E1U06DBVR` | si | Listo. |
| SMF12CT1G | SMF12CT1G | pendiente | `SOT-363-6_SMF12CT1G` | si | Footprint mecanico listo; falta pinout funcional. |
| PTC 1812 | 1812L050/30PR | `F_1812L050_30PR` | `Fuse_1812_4532Metric_Littelfuse_1812L050-30PR` | no | Listo mecanicamente. |
| Yageo 2.49k | RT0805BRD072K49L | `R_RT0805BRD` | `R_0805_2012Metric_Yageo_RT0805BRD` | si | Listo. |
| Yageo 1k | RT0805BRD071KL | `R_RT0805BRD` | `R_0805_2012Metric_Yageo_RT0805BRD` | si | Listo. |
| Yageo 49.9R | RT0805BRD0749R9L | `R_RT0805BRD` | `R_0805_2012Metric_Yageo_RT0805BRD` | si | Listo. |
| Yageo 200R | RT0805BRD07200RL | `R_RT0805BRD` | `R_0805_2012Metric_Yageo_RT0805BRD` | si | Listo. |
| Yageo 10k | RT0805BRD0710KL | `R_RT0805BRD` | `R_0805_2012Metric_Yageo_RT0805BRD` | si | Listo. |
| Yageo 73.2k | RT0805BRD0773K2L | `R_RT0805BRD` | `R_0805_2012Metric_Yageo_RT0805BRD` | si | Listo. |
| AVX 100nF | 08055C104K4T2A | `C_08055C104K4T2A` | `C_0805_2012Metric_AVX_08055C104K4T2A` | si | Listo con STEP del ZIP. |
| AVX 10nF | 08055C103K4T2A | `C_08055C103K4T2A` | `C_0805_2012Metric` | no | Footprint 0805 listo; falta STEP exacto. |
| AVX 33nF | KGM21NR71H333KT | `C_KGM21NR71H333KT` | `C_0805_2012Metric` | no | Footprint 0805 listo; no confundir con ZIP 08055C333KAT2A. |
| TDK 1uF | C2012X7R1H105K085AC | `C_C2012X7R1H105K085AC` | `C_0805_2012Metric_TDK_C2012X7R1H105K085AC` | si | Listo. |
| Murata 10uF | GRM21BR61E106KA73K | `C_GRM21BR61E106KA73K` | `C_0805_2012Metric` | no | Footprint 0805 listo; falta STEP exacto. |
| METZ 4 pos | AST0250404 | `SM50_4WIRE_CONN` | `TerminalBlock_METZ_AST0250404_1x04_P5.00mm` | no | Listo mecanicamente, paso 5.00 mm. |
| METZ 3 pos | AST0250304 | `PT100_3WIRE_CONN` / `PWR_BIPOLAR_3PIN` | `TerminalBlock_METZ_AST0250304_1x03_P5.00mm` | no | Listo mecanicamente, paso 5.00 mm; revisar cantidad comprada contra cantidad real de conectores. |
| Bourns trimmer | 3296W-1-102LF | `RV_3296W_1_102LF` | `Potentiometer_Bourns_3296W_1x03_P2.54mm` | no | Listo; footprint usa orden fisico de pads 1-3-2. |
| TE 160R | CPF0805B160RE1 | `R_CPF0805` | `R_0805_2012Metric` | no | Footprint 0805 listo. |
| TE 180R | CPF0805B180RE1 | `R_CPF0805` | `R_0805_2012Metric` | no | Footprint 0805 listo. |
| TE 200R | CPF0805B200RE1 | `R_CPF0805` | `R_0805_2012Metric` | no | Footprint 0805 listo. |
| Bel MagJack | 2250066-1 | `J_2250066_1_MAGJACK` | `RJ45_BelFuse_2250066-1` | si | Footprint desde drawing Bel; revisar calce 3D visual. |

## Observaciones importantes

- La orden compra `KGM21NR71H333KT` para 33 nF. El ZIP anterior `08055C333KAT2A` no corresponde exactamente a ese MPN.
- La orden compra borneras METZ `AST0250304` y `AST0250404` de 5.00 mm, no 5.08 mm.
- El conector `2250066-1` es Bel Fuse/TRP en la orden, no TE.
- El modelo 3D Yageo ya no esta en el resistor 0805 generico; quedo en el footprint especifico Yageo.

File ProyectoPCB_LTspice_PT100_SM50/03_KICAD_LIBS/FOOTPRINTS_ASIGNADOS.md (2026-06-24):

# Footprints KiCad para PT100 y SM50

Esta carpeta contiene una libreria local de KiCad para que los footprints no dependan
de rutas absolutas ni de librerias globales de otra instalacion.

## Archivos principales

- `ProyectoPCB.kicad_sym`: simbolos KiCad con pinout fisico o asignacion mecanica.
- `ProyectoPCB.pretty/`: footprints locales.
- `3dmodels/`: modelos STEP/STP copiados desde ZIPs o fuente de fabricante.
- `CRUCE_ORDEN_COMPRA_DK99915123.md`: cruce entre la orden DigiKey y la libreria local.

## Regla importante

No asignes solo un SOIC-8 generico a cualquier INA. El INA826 y el INA828 pueden usar
encapsulados SOIC-8, pero no son pin-compatibles. Usa el simbolo correcto:

- INA826: `ProyectoPCB:INA826_SOIC8`
- INA828: `ProyectoPCB:INA828_SOIC8`

En `01_SENSOR_PT100/Sensor_PT100.asc`, U1 usa `INA826`, aunque el texto del bloque
menciona INA828. Para PCB, decide cual integrado vas a montar y usa su simbolo KiCad
correspondiente.

## Asignaciones recomendadas

| Circuito | Referencias | Simbolo KiCad | Footprint |
| --- | --- | --- | --- |
| PT100 | Resistencias Yageo RT0805 de la compra | `ProyectoPCB:R_RT0805BRD` | `ProyectoPCB:R_0805_2012Metric_Yageo_RT0805BRD` |
| PT100 | Resistencias TE CPF0805 de la compra | `ProyectoPCB:R_CPF0805` | `ProyectoPCB:R_0805_2012Metric` |
| PT100 | Otras resistencias 0805 | `ProyectoPCB:R_0805` | `ProyectoPCB:R_0805_2012Metric` |
| PT100 | C1, C3, C4 si son 100nF AVX | `ProyectoPCB:C_08055C104K4T2A` | `ProyectoPCB:C_0805_2012Metric_AVX_08055C104K4T2A` |
| PT100 | C2 si usas el TDK 1uF | `ProyectoPCB:C_C2012X7R1H105K085AC` | `ProyectoPCB:C_0805_2012Metric_TDK_C2012X7R1H105K085AC` |
| PT100 | U1 actual del `.asc` | `ProyectoPCB:INA826_SOIC8` | `ProyectoPCB:SOIC-8_3.9x4.9mm_P1.27mm_INA826AIDR` |
| PT100 | U2 si montas OPA2188AIDR | `ProyectoPCB:OPA2188_SOIC8` | `ProyectoPCB:SOIC-8_3.9x4.9mm_P1.27mm_OPA2188AIDR` |
| PT100 | U4 / REF30E1_IDEAL | `ProyectoPCB:REF30E_SOT23` | `ProyectoPCB:SOT-23-3` |
| PT100 | Sensor RTD 3 hilos | `ProyectoPCB:PT100_3WIRE_CONN` | `ProyectoPCB:TerminalBlock_METZ_AST0250304_1x03_P5.00mm` |
| PT100 | Alimentacion +15/GND/-15 | `ProyectoPCB:PWR_BIPOLAR_3PIN` | `ProyectoPCB:TerminalBlock_METZ_AST0250304_1x03_P5.00mm` |
| PT100 | Salida a BBOX | `ProyectoPCB:BBOX_OUT_2PIN` | `ProyectoPCB:TerminalBlock_1x02_P5.08mm` |
| SM50 | Resistencias Yageo RT0805 de la compra | `ProyectoPCB:R_RT0805BRD` | `ProyectoPCB:R_0805_2012Metric_Yageo_RT0805BRD` |
| SM50 | Resistencias TE CPF0805 de la compra | `ProyectoPCB:R_CPF0805` | `ProyectoPCB:R_0805_2012Metric` |
| SM50 | C5 si compras KGM21 33nF | `ProyectoPCB:C_KGM21NR71H333KT` | `ProyectoPCB:C_0805_2012Metric` |
| SM50 | C5 si usas el ZIP 08055C333KAT2A | `ProyectoPCB:C_08055C333KAT2A` | `ProyectoPCB:C_0805_2012Metric_AVX_08055C333KAT2A` |
| SM50 | C3, C4 de 10nF AVX | `ProyectoPCB:C_08055C103K4T2A` | `ProyectoPCB:C_0805_2012Metric` |
| SM50 | C1, C2 de 10uF Murata | `ProyectoPCB:C_GRM21BR61E106KA73K` | `ProyectoPCB:C_0805_2012Metric` |
| SM50 | U2 | `ProyectoPCB:INA826_SOIC8` | `ProyectoPCB:SOIC-8_3.9x4.9mm_P1.27mm_INA826AIDR` |
| SM50 | U1 simplificado | `ProyectoPCB:TPS7A4701_10V_MODULE` | `ProyectoPCB:TPS7A4701_10V_Module_5Pin_P2.54mm` |
| SM50 | Regulador TPS7A4901 fisico, si redisenas esa etapa | `ProyectoPCB:TPS7A4901DGNT` | `ProyectoPCB:HVSSOP-8-1EP_DGN0008G_TPS7A4901DGNT` |
| SM50 | Celda SM50 / puente | `ProyectoPCB:SM50_4WIRE_CONN` | `ProyectoPCB:TerminalBlock_METZ_AST0250404_1x04_P5.00mm` |
| SM50 | Alimentacion +15/GND/-15 | `ProyectoPCB:PWR_BIPOLAR_3PIN` | `ProyectoPCB:TerminalBlock_METZ_AST0250304_1x03_P5.00mm` |
| SM50 | Salida a BBOX | `ProyectoPCB:BBOX_OUT_2PIN` | `ProyectoPCB:TerminalBlock_1x02_P5.08mm` |

## Componentes de la orden y ZIPs

| Componente | Simbolo KiCad | Footprint | Estado |
| --- | --- | --- | --- |
| INA826AIDR | `ProyectoPCB:INA826_SOIC8` | `ProyectoPCB:SOIC-8_3.9x4.9mm_P1.27mm_INA826AIDR` | Pinout y 3D enlazados. |
| OPA2188AIDR | `ProyectoPCB:OPA2188_SOIC8` | `ProyectoPCB:SOIC-8_3.9x4.9mm_P1.27mm_OPA2188AIDR` | Pinout y 3D enlazados. |
| REF3012AIDBZR | `ProyectoPCB:REF30E_SOT23` | `ProyectoPCB:SOT-23-3` | Pinout y 3D enlazados. |
| TPD4E1U06DBVR | `ProyectoPCB:TPD4E1U06DBVR` | `ProyectoPCB:SOT-23-6_DBV0006A_TPD4E1U06DBVR` | Pinout, footprint y 3D enlazados. |
| TPS7A4901DGNT | `ProyectoPCB:TPS7A4901DGNT` | `ProyectoPCB:HVSSOP-8-1EP_DGN0008G_TPS7A4901DGNT` | Pinout, PowerPAD y 3D enlazados. |
| SMF12CT1G | pendiente | `ProyectoPCB:SOT-363-6_SMF12CT1G` | Footprint mecanico y 3D listos; falta confirmar pinout. |
| 2250066-1 | `ProyectoPCB:J_2250066_1_MAGJACK` | `ProyectoPCB:RJ45_BelFuse_2250066-1` | Footprint desde drawing Bel C-2250066 y STEP enlazado; revisar ajuste 3D visual. |
| 1812L050/30PR | `ProyectoPCB:F_1812L050_30PR` | `ProyectoPCB:Fuse_1812_4532Metric_Littelfuse_1812L050-30PR` | Footprint listo; sin 3D local. |
| 3296W-1-102LF | `ProyectoPCB:RV_3296W_1_102LF` | `ProyectoPCB:Potentiometer_Bourns_3296W_1x03_P2.54mm` | Footprint listo; sin 3D local. |
| AST0250304 | `ProyectoPCB:PT100_3WIRE_CONN` o `ProyectoPCB:PWR_BIPOLAR_3PIN` | `ProyectoPCB:TerminalBlock_METZ_AST0250304_1x03_P5.00mm` | Paso 5.00 mm, sin 3D local. |
| AST0250404 | `ProyectoPCB:SM50_4WIRE_CONN` | `ProyectoPCB:TerminalBlock_METZ_AST0250404_1x04_P5.00mm` | Paso 5.00 mm, sin 3D local. |
| RT0805BRD07... | `ProyectoPCB:R_RT0805BRD` | `ProyectoPCB:R_0805_2012Metric_Yageo_RT0805BRD` | 3D Yageo enlazado solo a este footprint especifico. |
| CPF0805... | `ProyectoPCB:R_CPF0805` | `ProyectoPCB:R_0805_2012Metric` | 0805 mecanico; sin STEP exacto local. |
| 08055C104K4T2A | `ProyectoPCB:C_08055C104K4T2A` | `ProyectoPCB:C_0805_2012Metric_AVX_08055C104K4T2A` | STEP de DigiKey enlazado; land pattern oficial AVX pendiente. |
| 08055C103K4T2A | `ProyectoPCB:C_08055C103K4T2A` | `ProyectoPCB:C_0805_2012Metric` | 0805 mecanico; sin STEP exacto local. |
| KGM21NR71H333KT | `ProyectoPCB:C_KGM21NR71H333KT` | `ProyectoPCB:C_0805_2012Metric` | 0805 mecanico; sin STEP exacto local. |
| 08055C333KAT2A | `ProyectoPCB:C_08055C333KAT2A` | `ProyectoPCB:C_0805_2012Metric_AVX_08055C333KAT2A` | Este venia en ZIP, pero no es el MPN 33nF comprado. |
| C2012X7R1H105K085AC | `ProyectoPCB:C_C2012X7R1H105K085AC` | `ProyectoPCB:C_0805_2012Metric_TDK_C2012X7R1H105K085AC` | TDK confirma C2012/EIA 0805; STEP enlazado. |
| GRM21BR61E106KA73K | `ProyectoPCB:C_GRM21BR61E106KA73K` | `ProyectoPCB:C_0805_2012Metric` | 0805 mecanico; sin STEP exacto local. |

## Nota sobre TPS7A4701

El simbolo LTspice actual `TPS7A4701_10V` tiene solo 5 pines: `IN`, `EN`, `GND`,
`NR`, `OUT`. Por eso la libreria incluye un footprint de modulo/header de 5 pines.
Ese footprint no representa el integrado TPS7A4701 fisico completo. Si vas a montar
el IC real, hay que crear el simbolo completo del TPS7A4701 y asignar su encapsulado
real antes de fabricar.

Nota adicional: `TPS7A4901DGNT` no es `TPS7A4701`. El footprint/simbolo de
`TPS7A4901DGNT` esta disponible, pero no debe reemplazar automaticamente el bloque
LTspice `TPS7A4701_10V`.

## Fuentes de pinout y land pattern consultadas

- INA826: https://www.ti.com/lit/ds/symlink/ina826.pdf
- INA828: https://www.ti.com/lit/ds/symlink/ina828.pdf
- OPA188: https://www.ti.com/lit/ds/symlink/opa188.pdf
- OPA2188: https://www.ti.com/lit/ds/symlink/opa2188.pdf
- REF30E: https://www.ti.com/lit/ds/symlink/ref30e.pdf
- TPD4E1U06: https://www.ti.com/lit/ds/symlink/tpd4e1u06.pdf
- TPS7A49/TPS7A4901: https://www.ti.com/lit/ds/symlink/tps7a49.pdf
- TDK C2012X7R1H105K085AC: https://product.tdk.com/en/search/capacitor/ceramic/mlcc/info?part_no=C2012X7R1H105K085AC
- Bel 2250066-1: https://www.belfuse.com/products/ethernet/magjacks-icms/2250066-1
- Bel drawing C-2250066: https://www.belfuse.com/media/drawings/products/magjack%20ICMs/dr-mag-2250066.pdf
- Littelfuse 1812L: https://www.littelfuse.com/~/media/electronics/datasheets/resettable_ptcs/littelfuse_ptc_1812l_datasheet.pdf.pdf
- Bourns 3296: https://www.bourns.com/docs/Product-Datasheets/3296.pdf

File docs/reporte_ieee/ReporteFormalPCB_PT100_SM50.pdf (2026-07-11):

# Diseño e implementación de una tarjeta de acondicionamiento de señales para sensores de torque y temperatura en un motor de inducción

Kenneth Daniel Vizcaíno Jiménez
Escuela de Ingeniería Eléctrica Universidad de Costa Rica
San José, Costa Rica
kenneth.vizcaino@ucr.ac.cr

Resumen—Este reporte documenta el diseño de una tarjeta de acondicionamiento para sensores de torque y temperatura instalados en un motor de inducción del LabCES. El propósito del proyecto es adaptar las señales de un PT100 y una celda SM-50 para facilitar su adquisición y monitoreo en el banco de pruebas. El trabajo partió de modelos eléctricos, se verificó en LTspice y se trasladó a KiCad para obtener una PCB lista para fabricación. El PT100 se excitó con baja corriente para reducir autocalentamiento y el SM-50 se amplificó hasta ±4,39 V, dentro del rango de ±5 V de la B-Box. El resultado actual incluye simulaciones, esquemático, PCB, validación ERC/DRC y paquete Gerber; la prueba con prototipo físico queda como cierre posterior.
Index Terms—PT100, SM-50, motor de inducción, puente Wheatstone, INA826, LTspice, KiCad, acondicionamiento de señal, B-Box.
I. INTRODUCCIÓN

El proyecto nace de una necesidad práctica: medir temperatura y torque en un motor trifásico de inducción sin depender de señales crudas, pequeñas o vulnerables al ruido. En el banco del LabCES, estas variables apoyan el análisis del desempeño del motor, por lo que la PCB se planteó como una etapa intermedia entre los sensores y la interfaz de adquisición. El objetivo general propuesto fue diseñar e implementar una tarjeta de circuito impreso que acondicione y adapte esas señales para facilitar su adquisición y monitoreo.
La propuesta se organizó alrededor de cuatro objetivos específicos: comprender el diseño de PCB aplicado al acondicionamiento de señales con KiCad; verificar los sensores mediante pruebas o antecedentes reales disponibles; diseñar la PCB del circuito de acondicionamiento; e implementar y probar el prototipo dentro del sistema del motor. Como entregables se propusieron repositorio Git, diseño completo, prototipo físico, manual de instalación y uso, y sistema probado en el banco del LabCES.
Este documento reporta el estado técnico alcanzado: diseño electrónico completo, simulación, justificación de valores, diseño en KiCad y paquete de fabricación. Los entregables que dependen de una PCB ensamblada se presentan como pendientes de validación experimental, no como resultados ya ejecutados.

II. CRITERIOS DE DISEÑO
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

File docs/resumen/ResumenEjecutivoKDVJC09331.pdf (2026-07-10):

## Resumen ejecutivo

## PCB de acondicionamiento de señal para sensores PT100 y SM-50

IE0499 – Proyecto Eléctrico

Actividad evaluativa: resumen ejecutivo

27 de junio de 2026

Estudiante: Kenneth Daniel Vizcaíno Jiménez

Carné: C09331

Docente: Jaime Cascante Vindas

IE0499 – Proyecto Eléctrico | Resumen ejecutivo

## 1. Mensaje principal
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

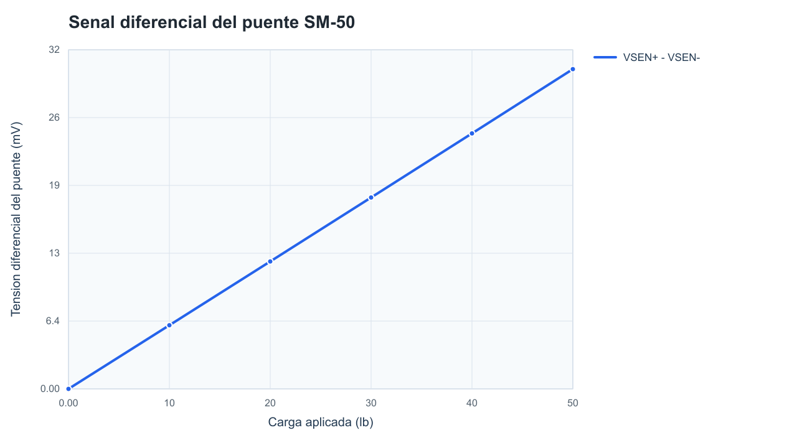
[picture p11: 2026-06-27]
docs/figuras/sm50_puente.png

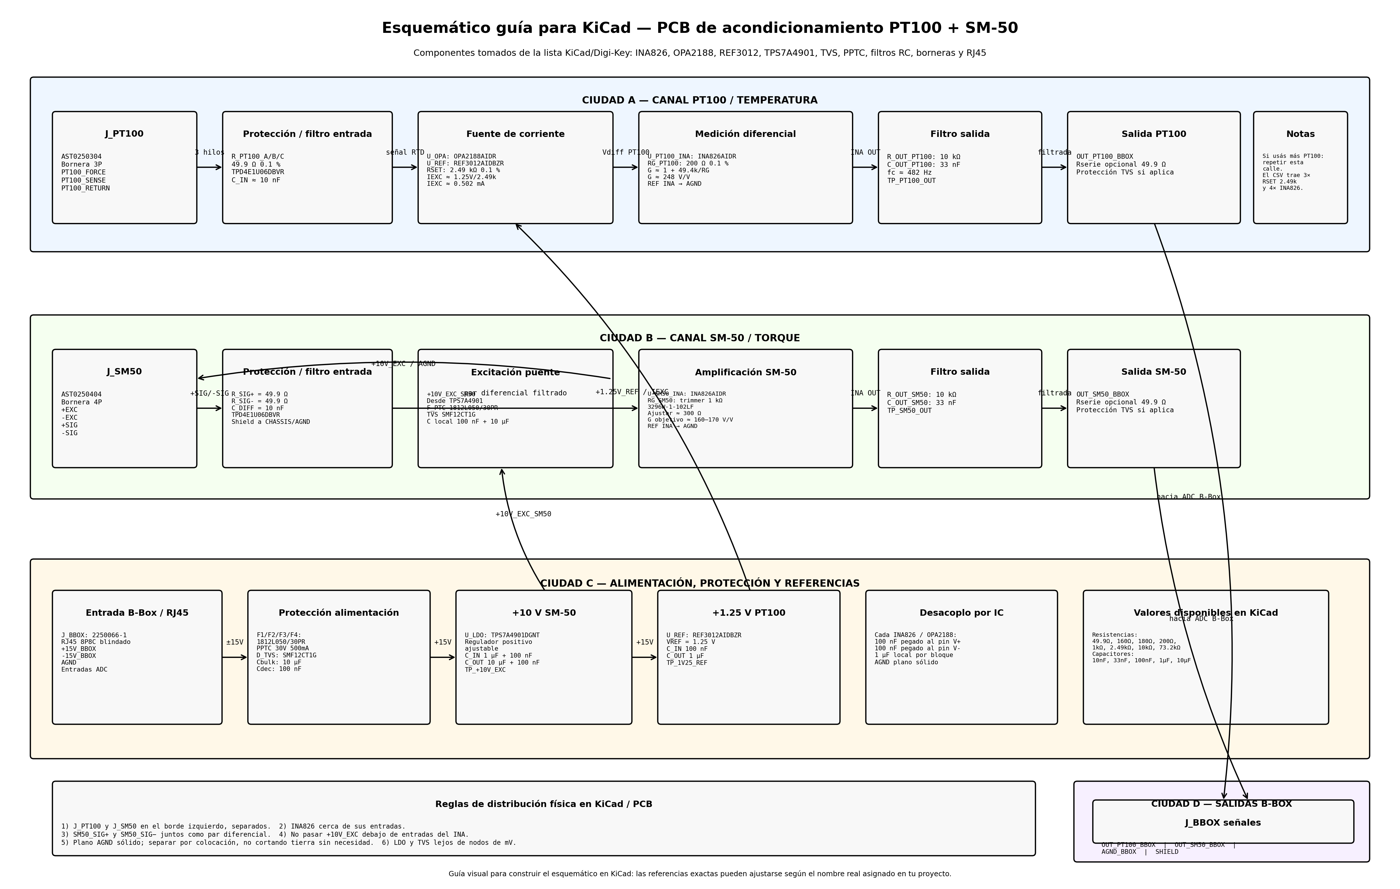
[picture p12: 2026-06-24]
PCB_PT100_SM50/docs/esquematico_detallado_kicad_PT100_SM50.png

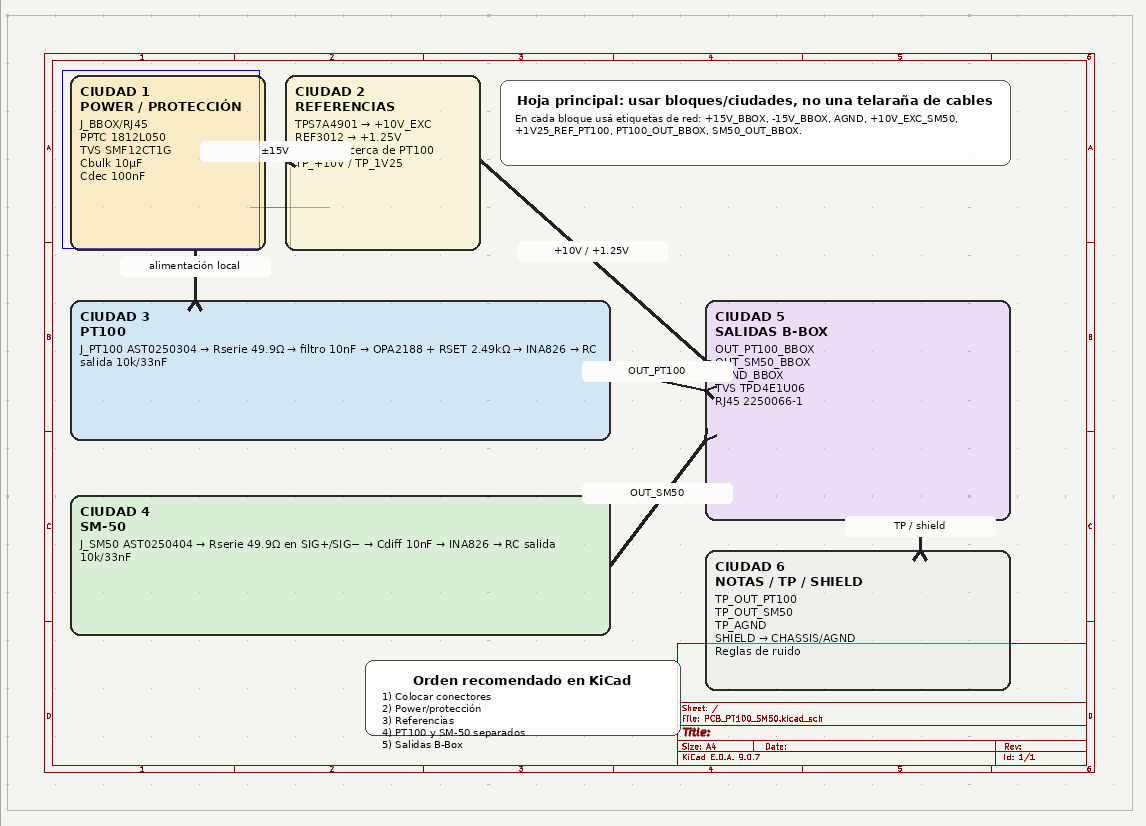
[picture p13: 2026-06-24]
PCB_PT100_SM50/docs/kiCad_hoja_ciudades_PT100_SM50_anotada.png

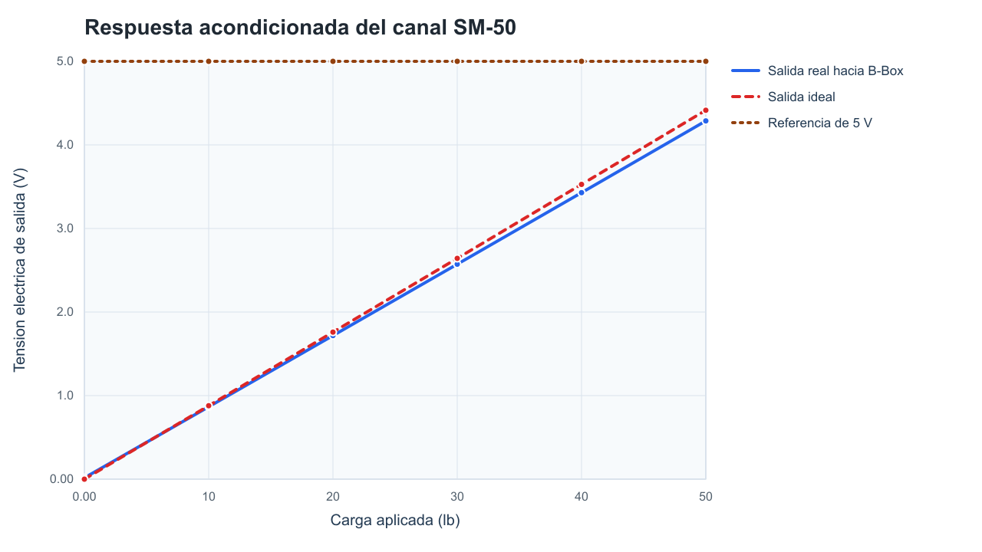
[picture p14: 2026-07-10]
docs/figuras/respuesta_sm50.png

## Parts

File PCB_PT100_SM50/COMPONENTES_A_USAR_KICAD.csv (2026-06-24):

Ciudad | Referencia sugerida | Cantidad | Símbolo KiCad a colocar | Valor en KiCad | Footprint a asignar | Componente real / MPN | Nota
POWER / B-Box | J_BBOX_PWR o J_BBOX | 1-2 | Connector:RJ45_Shielded | RJ45 8P8C | ProyectoPCB:2250066-1 | 2250066-1 | Usar footprint importado si lo tienes
POWER / Protección | F1 F2 F3 F4 | 4 | Device:Polyfuse | 500mA | Fuse:Fuse_1812_4532Metric | 1812L050/30PR | PPTC 1812
POWER / Protección | D_TVS_PWR1 D_TVS_PWR2 | 2 | Device:D_TVS | 12V | ProyectoPCB:SMF12CT1G o footprint importado | SMF12CT1G | SC88 / verificar footprint importado
POWER / Regulador +10V | U_LDO | 1 | TPS7A4901DGNT o símbolo importado | TPS7A4901DGNT | ProyectoPCB:TPS7A4901DGNT o Package_SO:MSOP-8-1EP_3x3mm_P0.65mm | TPS7A4901DGNT | Revisar pad térmico
POWER / Regulador +10V | R_ADJ1 | 1 | Device:R | 73.2k | Resistor_SMD:R_0805_2012Metric | RT0805BRD0773K2L | Ajuste LDO si aplica
POWER / Regulador +10V | R_ADJ2 | 1 | Device:R | 10k o 1k | Resistor_SMD:R_0805_2012Metric | RT0805BRD0710KL / RT0805BRD071KL | Ajuste LDO si aplica
REFERENCIA PT100 | U_REF | 1 | REF3012AIDBZR o símbolo importado | REF3012AIDBZR | Package_TO_SOT_SMD:SOT-23 | REF3012AIDBZR | Referencia 1.25V
REFERENCIA PT100 | C_REF_IN | 1 | Device:C | 100nF | Capacitor_SMD:C_0805_2012Metric | 08055C104K4T2A | Cerca del REF3012
REFERENCIA PT100 | C_REF_OUT | 1 | Device:C | 1uF | Capacitor_SMD:C_0805_2012Metric | C2012X7R1H105K085AC | Cerca del REF3012
PT100 | J_PT100 | 1 | Connector_Generic:Conn_01x03 | PT100 3 hilos | ProyectoPCB:AST0250304 | AST0250304 | Bornera 3P importada
PT100 | U_OPA_PT100 | 1-2 | OPA2188AIDR o símbolo importado | OPA2188AIDR | Package_SO:SOIC-8_3.9x4.9mm_P1.27mm | OPA2188AIDR | Dual op-amp, fuente de corriente/buffer
PT100 | U_INA_PT100x | 1 por canal | INA826AIDR o símbolo importado | INA826AIDR | Package_SO:SOIC-8_3.9x4.9mm_P1.27mm | INA826AIDR | INA para PT100
PT100 | RSET_PT100x | 3 | Device:R | 2.49k 0.1% | Resistor_SMD:R_0805_2012Metric | RT0805BRD072K49L | Iexc ≈ 0.5mA con 1.25V
PT100 | R_IN_PT100x | varias | Device:R | 49.9R | Resistor_SMD:R_0805_2012Metric | RT0805BRD0749R9L | Serie/filtro entrada
PT100 | RG_PT100x | 1 por INA | Device:R | 200R | Resistor_SMD:R_0805_2012Metric | RT0805BRD07200RL / CPF0805B200RE1 | Ganancia INA, ajustar según cálculo
PT100 | C_IN_PT100x | varias | Device:C | 10nF | Capacitor_SMD:C_0805_2012Metric | 08055C103K4T2A | Filtro entrada
PT100 | R_OUT_PT100x | 1 por salida | Device:R | 10k | Resistor_SMD:R_0805_2012Metric | RT0805BRD0710KL | Filtro salida
PT100 | C_OUT_PT100x | 1 por salida | Device:C | 33nF | Capacitor_SMD:C_0805_2012Metric | KGM21NR71H333KT | Filtro salida
SM-50 | J_SM50 | 1 | Connector_Generic:Conn_01x04 | SM-50 4 hilos | ProyectoPCB:AST0250404 | AST0250404 | Bornera 4P importada
SM-50 | U_INA_SM50 | 1 | INA826AIDR o símbolo importado | INA826AIDR | Package_SO:SOIC-8_3.9x4.9mm_P1.27mm | INA826AIDR | INA torque
SM-50 | R_SIG_P/R_SIG_N | 2 | Device:R | 49.9R | Resistor_SMD:R_0805_2012Metric | RT0805BRD0749R9L | Serie entrada diferencial
SM-50 | C_DIFF_SM50 | 1 | Device:C | 10nF | Capacitor_SMD:C_0805_2012Metric | 08055C103K4T2A | Filtro diferencial SIG+/SIG-
SM-50 | RG_SM50 | 1 | Device:R o Device:R_Potentiometer_Trim | 160R/180R/200R o 1k trim | Resistor_SMD:R_0805_2012Metric o Potentiometer_THT:Potentiometer_Bourns_3296W_Vertical | CPF0805B160RE1 / CPF0805B180RE1 / CPF0805B200RE1 / 3296W-1-102LF | Elegir una opción de ganancia
SM-50 | R_OUT_SM50 | 1 | Device:R | 10k | Resistor_SMD:R_0805_2012Metric | RT0805BRD0710KL | Filtro salida
SM-50 | C_OUT_SM50 | 1 | Device:C | 33nF | Capacitor_SMD:C_0805_2012Metric | KGM21NR71H333KT | Filtro salida
ESD / Salidas | D_ESD1 D_ESD2 D_ESD3 | 3 | Device:D_TVS_x4 o símbolo importado | TPD4E1U06DBVR | Package_TO_SOT_SMD:SOT-23-6 | TPD4E1U06DBVR | Protección ESD señales
Desacoplos | C_DEC_x | varios | Device:C | 100nF | Capacitor_SMD:C_0805_2012Metric | 08055C104K4T2A | Uno cerca de cada IC
Bulk local | C_BULK_x | varios | Device:C | 10uF | Capacitor_SMD:C_0805_2012Metric | GRM21BR61E106KA73K | Entrada/salida regulador
Bulk local | C_1U_x | varios | Device:C | 1uF | Capacitor_SMD:C_0805_2012Metric | C2012X7R1H105K085AC | Refs/regulador/local

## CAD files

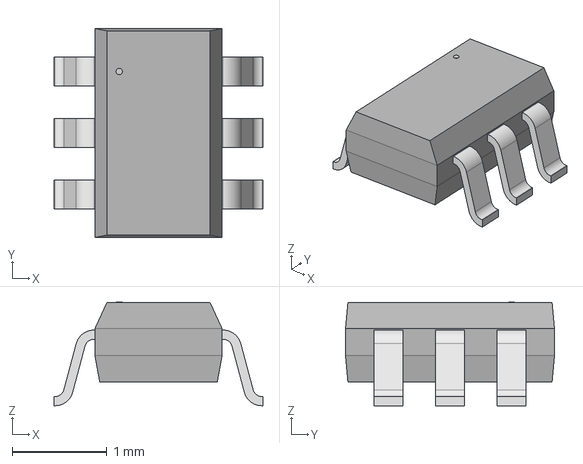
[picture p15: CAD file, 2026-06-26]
PCB_PT100_SM50/3d/SOT-363-6_2P2X1P35_ONS.step
2.21 x 2.21 x 1.09 mm

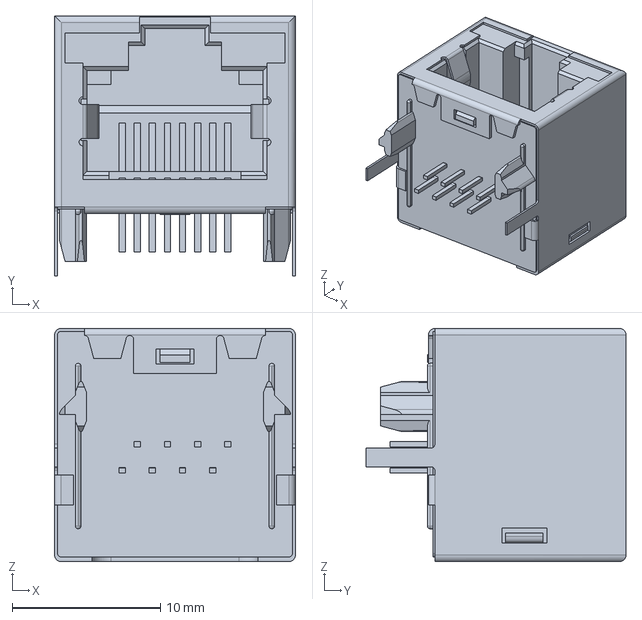
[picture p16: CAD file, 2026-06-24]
PCB_PT100_SM50/3d/RJ45_1-406541-5.step
16.3 x 17.6 x 15.7 mm

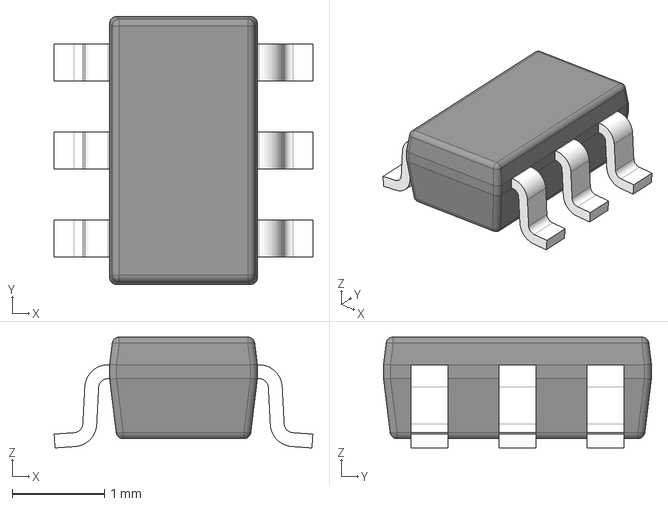
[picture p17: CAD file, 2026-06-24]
ProyectoPCB_LTspice_PT100_SM50/03_KICAD_LIBS/3dmodels/TPD4E1U06DBVR_TI_SOT23-6_DBV0006A.stp
2.80 x 2.90 x 1.20 mm
BODY-SOT
LEAD-SOT x 6

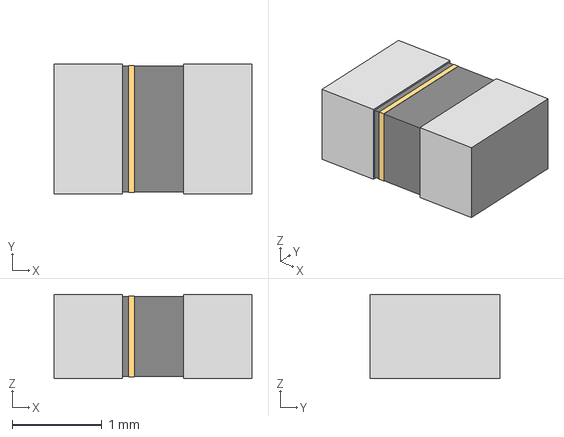
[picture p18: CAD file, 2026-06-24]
PCB_PT100_SM50/3d/CAP_X7R_0805_AVX.step
2.21 x 1.45 x 0.94 mm

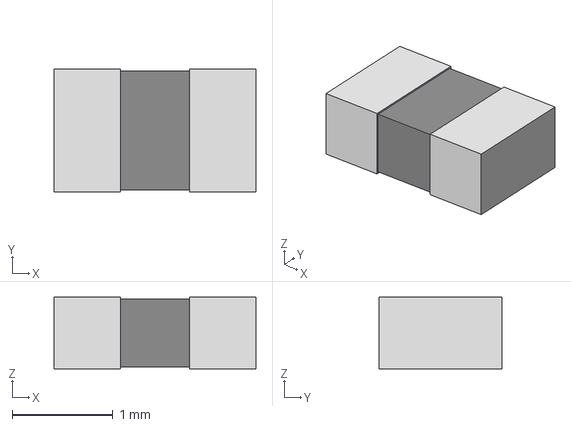
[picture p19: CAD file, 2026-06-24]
ProyectoPCB_LTspice_PT100_SM50/03_KICAD_LIBS/3dmodels/RT0805BRD_Yageo_0805.step
2.01 x 1.22 x 0.711 mm

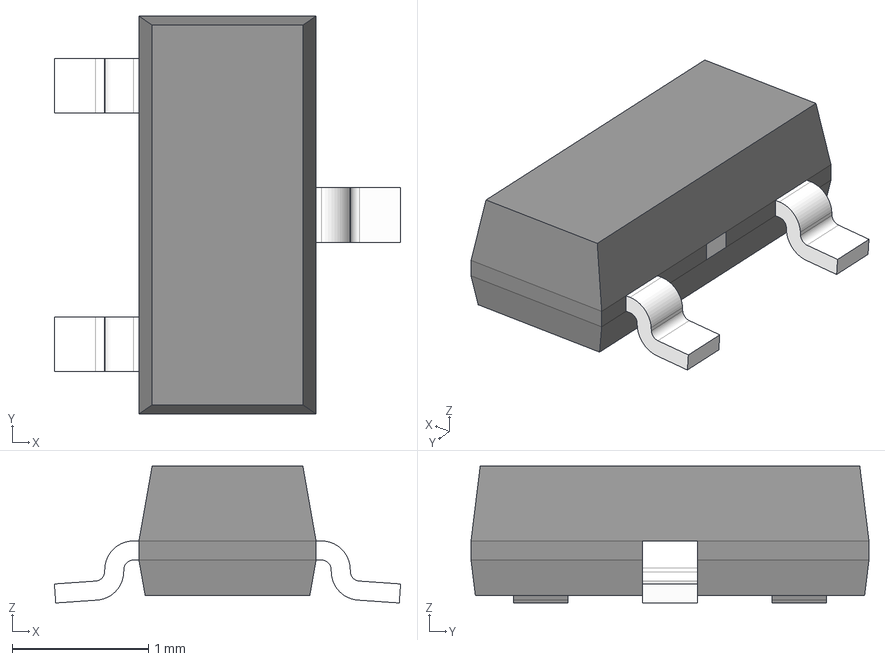
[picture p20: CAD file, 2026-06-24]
PCB_PT100_SM50/3d/DBZ0003A.stp
2.54 x 2.92 x 1.01 mm
BODY-SOT
LEAD-SOT x 3
PIN1-ID
TIEBAR

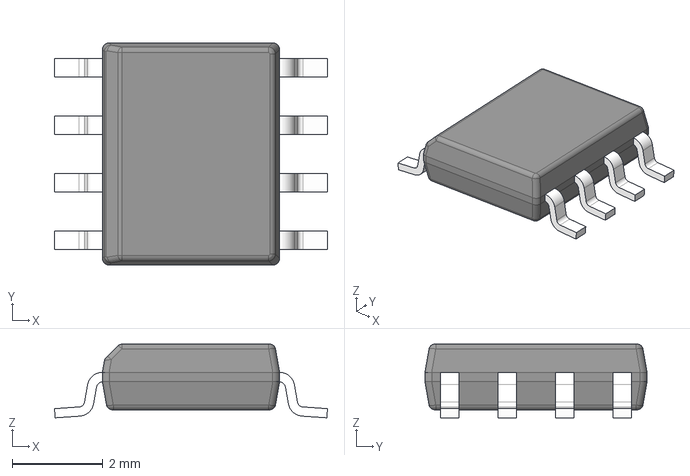
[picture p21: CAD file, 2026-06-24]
ProyectoPCB_LTspice_PT100_SM50/03_KICAD_LIBS/3dmodels/INA826AIDR_TI_SOIC8_D0008A.stp
6.02 x 4.90 x 1.63 mm
BODY-SO
LEAD-D0008A x 8

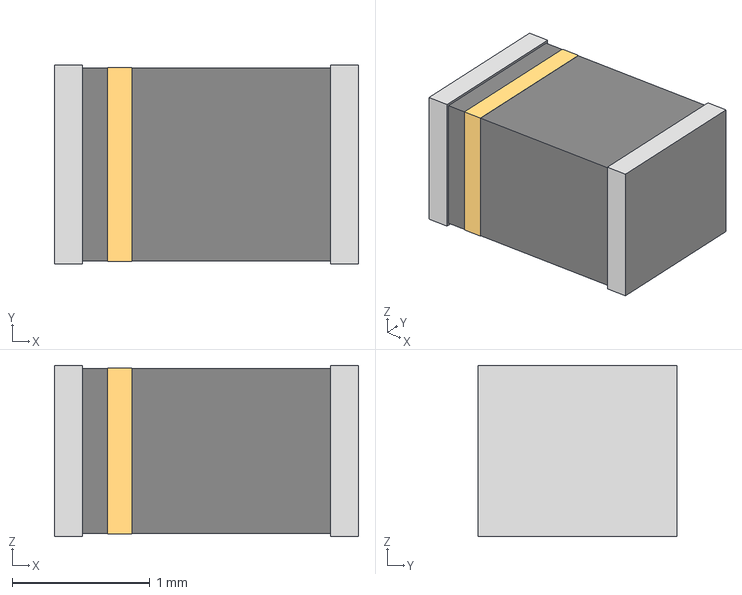
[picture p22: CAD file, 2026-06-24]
ProyectoPCB_LTspice_PT100_SM50/03_KICAD_LIBS/3dmodels/C2012X7R1H105K085AC_TDK_0805_1uF.step
2.21 x 1.45 x 1.25 mm

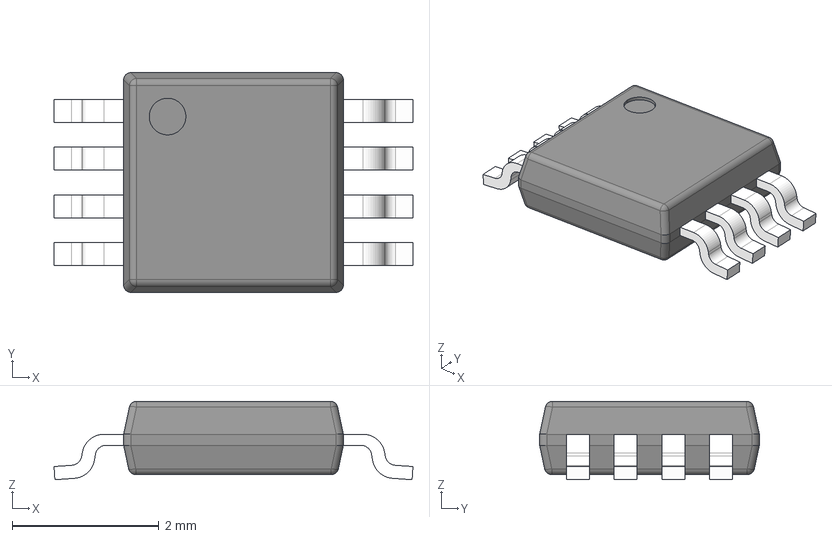
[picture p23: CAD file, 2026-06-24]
PCB_PT100_SM50/3d/DGN0008G.stp
4.90 x 3.00 x 1.07 mm
BODY-DGN0008G
LEAD-DGN0008G x 8
PIN1_DGN0008G
DAP_DGN0008G

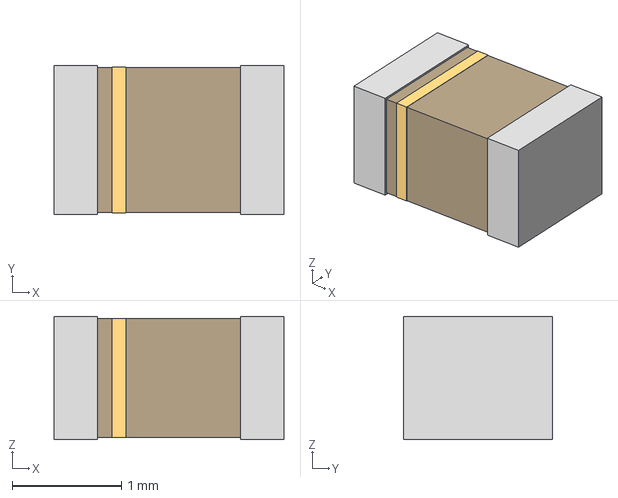
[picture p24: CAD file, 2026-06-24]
PCB_PT100_SM50/3d/CAP_0805_AVX.step
2.11 x 1.37 x 1.13 mm

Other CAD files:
PCB_PT100_SM50/3d/RC0805N_YAG.step
ProyectoPCB_LTspice_PT100_SM50/03_KICAD_LIBS/3dmodels/SMF12CT1G_ONS_SOT363-6.step
PCB_PT100_SM50/3d/2250066-1.step
PCB_PT100_SM50/3d/2250066-1.stl
PCB_PT100_SM50/3d/2250066-1.stp
PCB_PT100_SM50/3d/AST0250404.stp
ProyectoPCB_LTspice_PT100_SM50/03_KICAD_LIBS/3dmodels/2250066-1_BelFuse.stp

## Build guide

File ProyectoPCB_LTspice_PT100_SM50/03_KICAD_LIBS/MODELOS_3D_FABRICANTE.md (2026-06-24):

# Modelos 3D de fabricante

Los ZIPs indicados contienen modelos STEP/STP, no siempre footprints KiCad
completos. Copie los modelos dentro del proyecto para no depender de rutas en
`Downloads`.

Carpeta local:

```text
03_KICAD_LIBS/3dmodels/
```

## Modelos copiados

| Componente | Archivo local | Uso actual |
| --- | --- | --- |
| 2250066-1 | `2250066-1_BelFuse.stp` | Enlazado al footprint `RJ45_BelFuse_2250066-1`. El patron de taladros se tomo del drawing Bel/TRP C-2250066; revisar ajuste visual del STEP en KiCad antes de fabricar. |
| C2012X7R1H105K085AC | `C2012X7R1H105K085AC_TDK_0805_1uF.step` | Enlazado al footprint especifico `C_0805_2012Metric_TDK_C2012X7R1H105K085AC`. |
| 08055C333KAT2A | `08055C333KAT2A_AVX_0805_33nF.step` | Enlazado al footprint especifico `C_0805_2012Metric_AVX_08055C333KAT2A`. Ojo: la orden compra `KGM21NR71H333KT`, no este MPN. |
| 08055C104K4T2A | `08055C104K4T2A_AVX_0805_100nF.step` | Enlazado al footprint especifico `C_0805_2012Metric_AVX_08055C104K4T2A`. |
| RT0805BRD0710KL / 1KL / 200RL / 49R9L / 73K2L / 2K49L | `RT0805BRD_Yageo_0805.step` | Enlazado al footprint especifico `R_0805_2012Metric_Yageo_RT0805BRD`. |
| SMF12CT1G | `SMF12CT1G_ONS_SOT363-6.step` | Enlazado al footprint `SOT-363-6_SMF12CT1G`; falta confirmar simbolo/pinout antes de usarlo electricamente. |
| TPD4E1U06DBVR | `TPD4E1U06DBVR_TI_SOT23-6_DBV0006A.stp` | Enlazado al footprint y simbolo `TPD4E1U06DBVR`. |
| TPS7A4901DGNT | `TPS7A4901DGNT_TI_HVSSOP8_DGN0008G.stp` | Enlazado al footprint y simbolo `TPS7A4901DGNT`. |
| REF3012AIDBZR | `REF3012AIDBZR_TI_SOT23_DBZ0003A.stp` | Enlazado al footprint `SOT-23-3` y simbolo `REF30E_SOT23`. |
| OPA2188AIDR | `OPA2188AIDR_TI_SOIC8_D0008A.stp` | Enlazado al footprint especifico `SOIC-8_3.9x4.9mm_P1.27mm_OPA2188AIDR`. |
| INA826AIDR | `INA826AIDR_TI_SOIC8_D0008A.stp` | Enlazado al footprint especifico `SOIC-8_3.9x4.9mm_P1.27mm_INA826AIDR`. |

## Piezas de la orden sin STEP local exacto

| Componente | Estado |
| --- | --- |
| 08055C103K4T2A | Simbolo `C_08055C103K4T2A`, footprint generico `C_0805_2012Metric`, sin 3D exacto local. |
| KGM21NR71H333KT | Simbolo `C_KGM21NR71H333KT`, footprint generico `C_0805_2012Metric`, sin 3D exacto local. |
| GRM21BR61E106KA73K | Simbolo `C_GRM21BR61E106KA73K`, footprint generico `C_0805_2012Metric`, sin 3D exacto local. |
| CPF0805B160RE1 / 180RE1 / 200RE1 | Simbolo `R_CPF0805`, footprint generico `R_0805_2012Metric`, sin 3D exacto local. |
| 1812L050/30PR | Simbolo y footprint `Fuse_1812_4532Metric_Littelfuse_1812L050-30PR`, sin 3D local. |
| AST0250304 / AST0250404 | Footprints METZ a paso 5.00 mm, sin 3D local. |
| 3296W-1-102LF | Simbolo y footprint `Potentiometer_Bourns_3296W_1x03_P2.54mm`, sin 3D local. |

## Notas de uso

- Los modelos 3D estan enlazados con rutas relativas usando `${KIPRJMOD}/../03_KICAD_LIBS/3dmodels/...`.
- Si se abre `01_SENSOR_PT100/Sensor_PT100.kicad_pro` o un proyecto dentro de `02_SENSOR_SM50`, esas rutas siguen apuntando al mismo lugar.
- El footprint generico `R_0805_2012Metric` ya no tiene modelo 3D Yageo; el modelo Yageo quedo solo en `R_0805_2012Metric_Yageo_RT0805BRD`.
- Los footprints genericos `C_0805_2012Metric` y `SOIC-8_3.9x4.9mm_P1.27mm` no tienen modelo 3D especifico para evitar mostrar una pieza equivocada.

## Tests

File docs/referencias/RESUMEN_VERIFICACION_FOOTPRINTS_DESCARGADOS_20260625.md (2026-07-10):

# Verificacion de ZIPs de footprints/modelos - 2026-06-25

Proyecto: PCB_PT100_SM50

## Resultado ejecutivo

Los ZIPs se extrajeron y se compararon contra el BOM de compra
`PCB_PT100_SM50/bom/99915123_DigiKey_original.csv`, el BOM de entrega
`ENTREGA_PCB_PT100_SM50_20260625/ensamble/PCB_PT100_SM50_BOM.csv` y el PCB
actual `PCB_PT100_SM50/PCB_PT100_SM50.kicad_pcb`.

Actualización: se recibió y verificó también `INA826AIDR.zip`, que sí
corresponde al BOM actual. El footprint descargado `D8.kicad_mod` es SOIC-8,
pitch 1.27 mm, y es compatible con el footprint actual de U2/U4.

Actualización final de fabricación: se reemplazaron en el PCB los footprints
críticos que dependian de ZIPs descargados: `J_PT100_1` usa
`ProyectoPCB:CONN_AST0250304_MZC`, `J_SM50` usa `ProyectoPCB:AST0250404` y
`U3` usa `ProyectoPCB_Footprints:TPS7A4901DGNT_DGN8_1P89X1P57` con el pad
térmico renombrado a `9`. Después del reemplazo, KiCad ERC/DRC quedó en 0
violaciones y 0 pads sin conectar.

Corrección posterior de `J_PT100_1`: el footprint descargado para
`CONN_AST0250304_MZC` se ajustó localmente contra el datasheet METZ
`ST025xxHDNC AST025` / `AST025xx04`. Para 3 polos, la huella queda con largo
15 mm, profundidad PCB 11 mm, pitch 5.00 mm y taladro 1.4 mm.

Corrección adicional de `J_SM50`: se completó la huella embebida y la librería
local con serigrafía y `F.CrtYd`; se eliminó `allow_missing_courtyard`. El
lado cercano a `D1` queda con courtyard ajustado para encerrar cuerpo/silk sin
solapar el TVS. También se rellenaron los planos GND. DRC final:
`drc_after_pt100_sm50_terminal_fix_20260626.rpt` con 0 violaciones, 0 pads sin
conectar y 0 problemas de paridad esquemático-PCB.

El ZIP `INA826AIDGKR.zip` queda marcado como no aplicable para esta compra:
`AIDGKR` es encapsulado DGK/VSSOP-8 de pitch 0.65 mm, mientras el PCB actual y
la compra usan `INA826AIDR`, encapsulado SOIC-8 de pitch 1.27 mm.

## ZIPs revisados

| ZIP | Veredicto | Observación |
| --- | --- | --- |
| `LibraryLoaderSetup2v50.msi.zip` | No es componente | Es instalador de Library Loader; no contiene footprint específico para el PCB. |
| `AST0250304 (1).zip` | Base para J_PT100_1, corregido localmente | Trae `CONN_AST0250304_MZC.kicad_mod`. Coincide en 3 pines y pitch 5.00 mm, pero se ajustaron profundidad y taladro contra el datasheet METZ. |
| `LIB_AST0250404.zip` | Aplicado para J_SM50 | Trae KiCad nativo `AST0250404.kicad_mod` y 3D `AST0250404.stp`. Coincide en 4 pines y pitch 5.00 mm; reemplazo aplicado en el PCB. |
| `TPS7A4901DGNT.zip` | Aplicado para U3, con ajuste | Trae `DGN8_1P89X1P57.kicad_mod` y modelo STEP. Se adaptó el pad térmico de `EPAD` a `9` para coincidir con el símbolo actual. |
| `INA826AIDGKR.zip` | No usar con el BOM actual | Es DGK/VSSOP-8. El BOM compra `INA826AIDR`, SOIC-8. |
| `INA826AIDR.zip` | Compatible con U2/U4 | Trae `D8.kicad_mod`, SOIC-8. Coincide con el MPN del BOM y con el footprint actual. |
| `OPA2188AIDR.zip` | Compatible con U5 | Trae `D8.kicad_mod`, SOIC-8. El footprint actual KiCad SOIC-8 es prácticamente equivalente. |

## Comparación de medidas principales

| Parte | Footprint actual en PCB | Footprint descargado/local comparado | Resultado |
| --- | --- | --- | --- |
| J_PT100_1 / AST0250304 | `ProyectoPCB:CONN_AST0250304_MZC` corregido | Datasheet METZ `AST025xx04`: 3 pines, pitch 5.00 mm, cuerpo PCB 15 x 11 mm, pads 2.1 mm, drill 1.4 mm | OK corregido en PCB y librería local. |
| J_SM50 / AST0250404 | `ProyectoPCB:AST0250404` aplicado | ZIP `AST0250404`, pitch 5.00 mm, pads 2.1 mm, drill 1.4 mm, modelo `AST0250404.stp` | OK aplicado en PCB y esquemático; courtyard completado sin excepción DRC. |
| U3 / TPS7A4901DGNT | `ProyectoPCB_Footprints:TPS7A4901DGNT_DGN8_1P89X1P57` aplicado | ZIP `DGN8_1P89X1P57`, pads x +/-2.0955 mm, pad térmico 1.57 x 1.89 mm | OK aplicado; pad térmico adaptado a `9`. |
| U2/U4 / INA826AIDR | SOIC-8 3.9 x 4.9 mm, pitch 1.27 mm, span x 4.95 mm, pads 1.95 x 0.60 mm | ZIP correcto `D8`, pitch 1.27 mm, span x 4.928 mm, pads 1.9812 x 0.5588 mm | Coincide. El footprint actual es compatible. |
| U2/U4 / ZIP confundido INA826AIDGKR | SOIC-8 3.9 x 4.9 mm, pitch 1.27 mm | ZIP `DGK8`, pitch 0.65 mm, VSSOP/MSOP | No coincide. No usar para el BOM actual. |
| U5 / OPA2188AIDR | SOIC-8 3.9 x 4.9 mm, pitch 1.27 mm | ZIP `D8`, pitch 1.27 mm, pad span equivalente | Compatible. El footprint actual es aceptable. |

## Recomendación antes de mandar a fabricar

1. Mantener U2/U4 como SOIC-8 para `INA826AIDR`; el ZIP correcto `INA826AIDR.zip` confirma que el footprint actual calza.
2. U3 ya quedó con footprint DGN/HVSSOP-8 PowerPAD específico y pad térmico `9`.
3. J_PT100_1 quedó corregido contra datasheet METZ; J_SM50 mantiene footprint METZ descargado.
4. Mantener U5 como SOIC-8; el ZIP de OPA confirma que el footprint actual está bien.

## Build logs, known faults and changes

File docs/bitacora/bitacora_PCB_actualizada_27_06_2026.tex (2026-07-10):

\documentclass[12pt]{article}

% ------------------------------------------------
\usepackage[spanish]{babel}
\usepackage[utf8]{inputenc}
\usepackage[T1]{fontenc}
\usepackage{geometry}
\geometry{margin=2.5cm}
\usepackage{setspace}
\onehalfspacing
\usepackage{parskip}
\usepackage[hypertexnames=false]{hyperref}
\usepackage{fancyhdr}
\usepackage{siunitx}
\sisetup{per-mode=symbol}
\usepackage{float}
\usepackage{graphicx}
\usepackage{adjustbox}
\usepackage{tikz}
\usetikzlibrary{arrows.meta,positioning,shapes.geometric}

\pagestyle{fancy}
\fancyhf{}
\rhead{\thepage}
\setlength{\headheight}{14.5pt}

\begin{document}

% ------------------------------------------------
\begin{center}
\textbf{\Large Universidad de Costa Rica}\\
\vspace{0.3cm}
\textbf{Escuela de Ingeniería Eléctrica}

\vspace{2cm}

\textbf{\LARGE Bitácora de laboratorio}

\vspace{1.5cm}

\textbf{Diseño de PCB para Sensores de Torque y Temperatura}

\vspace{1.5cm}

Kenneth Daniel Vizcaíno Jiménez -- C09331

\vspace{1cm}

Marzo--Junio 2026
\end{center}

\newpage
\tableofcontents
\newpage

% =================================================
\section{Descripción del proyecto}

\textbf{Título del proyecto:}
Diseño e implementación de una tarjeta de acondicionamiento de señales para sensores de torque y temperatura en un motor de inducción.

\textbf{Objetivo general:}
Diseñar e implementar una PCB que permita acondicionar las señales de sensores para su correcta adquisición.

\textbf{Objetivos específicos:}
\begin{enumerate}
\item Comprender el diseño de PCB.
\item Verificar sensores.
\item Diseñar circuito.
\item Implementar prototipo.
\end{enumerate}

\textbf{Entregables:}
\begin{itemize}
\item Esquemático
\item PCB
\item Prototipo
\item Pruebas
\end{itemize}

% =================================================
\section{Bitácora de trabajo}

% =========================
\section{Primera semana}

\subsection{Inicio del proyecto}
\textbf{Fecha:} 11/03/2026 \quad \textbf{Hora:} 13:00--14:00

\textbf{Objetivo:}
Definir el enfoque del proyecto.

\textbf{Desarrollo:}
\begin{itemize}
\item Se realizó una revisión general del alcance del proyecto, identificando los requerimientos principales del sistema y los objetivos a cumplir en el diseño de la PCB.
\item Se planteó una primera idea conceptual del circuito, considerando la integración simultánea de sensores de temperatura y torque dentro de una misma tarjeta.
\item Se analizaron posibles configuraciones de conexión eléctrica, evaluando cómo se distribuirían las señales dentro del sistema.
\end{itemize}

\textbf{Resultados:}
Definición inicial del sistema.

\textbf{Dificultades:}
Incertidumbre sobre componentes.

% -------------------------
\subsection{Introducción a KiCad}
\textbf{Fecha:} 12/03/2026 \quad \textbf{Hora:} 13:00--17:00

\textbf{Objetivo:}
Aprender el entorno de KiCad.

\textbf{Desarrollo:}
\begin{itemize}
\item Se estudiaron tutoriales enfocados en el uso básico del software, permitiendo comprender la lógica de trabajo del entorno.
\item Se exploraron los conceptos de símbolos electrónicos y footprints, entendiendo su relación dentro del diseño.
\item Se revisaron distintas librerías de componentes disponibles para su implementación en el proyecto.
\end{itemize}

\textbf{Resultados:}
Comprensión funcional del software.

\textbf{Dificultades:}
Asociación símbolo-huella.

% -------------------------
\subsection{Práctica de PCB}
\textbf{Fecha:} 13/03/2026 \quad \textbf{Hora:} 11:00--16:00

\textbf{Objetivo:}
Practicar diseño.

\textbf{Desarrollo:}
\begin{itemize}
\item Se desarrolló un prototipo de PCB con fines de aprendizaje, sin ser aún el diseño final del proyecto.
\item Se trabajó en la colocación de componentes y su distribución dentro del área de la tarjeta.
\item Se asignaron footprints correspondientes a cada componente, fortaleciendo el flujo de trabajo.
\end{itemize}

\textbf{Resultados:}
Mayor dominio práctico.

\textbf{Dificultades:}
Orden del diseño.

% =========================
\section{Segunda semana}

\subsection{Profundización en diseño}
\textbf{Fecha:} 18/03/2026 \quad \textbf{Hora:} 15:00--23:00

\textbf{Objetivo:}
Mejorar diseño.

\textbf{Desarrollo:}
\begin{itemize}
\item Se trabajó en el diseño del plano de tierra, comprendiendo su importancia en la reducción de ruido.
\item Se ajustó el contorno físico de la PCB, definiendo su forma final.
\item Se importaron nuevas librerías para ampliar las opciones de diseño.
\item Se revisaron reglas eléctricas y de manufactura para evitar errores futuros.
\end{itemize}

\textbf{Resultados:}
Mayor comprensión global.

\textbf{Dificultades:}
Implementación de tierra.

% =========================
\section{Tercera semana}

\subsection{Ruido en sistemas}
\textbf{Fecha:} 25/03/2026 \quad \textbf{Hora:} 13:30--18:30

\textbf{Objetivo:}
Comprender ruido.

\textbf{Desarrollo:}
\begin{itemize}
\item Se analizaron diferentes fuentes de ruido presentes en sistemas electrónicos.
\item Se estudiaron efectos térmicos e interferencias externas.
\item Se evaluaron técnicas como filtrado, blindaje y cableado trenzado para mitigación.
\end{itemize}

\textbf{Resultados:}
Identificación de soluciones prácticas.

\textbf{Dificultades:}
Conceptos abstractos.

% -------------------------
\subsection{Sensores}
\textbf{Fecha:} 25/03/2026 \quad \textbf{Hora:} 13:30--17:30

\textbf{Objetivo:}
Analizar sensores.

\textbf{Desarrollo:}
\begin{itemize}
\item Se investigó el funcionamiento de sensores de torque y temperatura.
\item Se analizaron sus señales de salida y características eléctricas.
\item Se evaluaron requisitos de acondicionamiento para integración futura.
\end{itemize}

\textbf{Resultados:}
Comprensión del sistema.

\textbf{Dificultades:}
Rangos de señal.

% =========================
\section{Cuarta semana}

\subsection{Revisión técnica}
\textbf{Fecha:} 30/03/2026 \quad \textbf{Hora:} 13:30--19:30

\textbf{Objetivo:}
Refuerzo teórico.

\textbf{Desarrollo:}
\begin{itemize}
\item Se analizaron documentos técnicos relacionados con diseño de PCB.
\item Se estudiaron buenas prácticas de ingeniería.
\item Se relacionó la teoría con el proyecto en desarrollo.
\end{itemize}

\textbf{Resultados:}
Mejor criterio técnico.

\textbf{Dificultades:}
Interpretación normativa.

% =========================
\section{Quinta semana}

% -------------------------
\subsection{Desarrollo de arquitectura del sistema}
\textbf{Fecha:} 08/04/2026 \quad \textbf{Hora:} 13:00--20:00

\textbf{Objetivo:}
Definir formalmente la arquitectura completa del sistema de adquisición de señales para los sensores de torque y temperatura.

\textbf{Desarrollo:}
\begin{itemize}
\item Se elaboró un documento técnico completo donde se definió la arquitectura del sistema, estableciendo la cadena funcional desde los sensores hasta el controlador BoomBox.
\item Se planteó un diagrama de bloques estructurado considerando las etapas: sensor, transporte por cable RJ45/UTP, entrada a PCB, acondicionamiento analógico, interfaz ModuLink y digitalización en el sistema imperix.
\item Se analizó en detalle el comportamiento del sensor de torque basado en puente de Wheatstone, identificando que su salida es diferencial y de muy baja amplitud (del orden de milivoltios), lo que hace indispensable el uso de amplificación instrumental.
\item Se establecieron valores iniciales de diseño para el sensor de torque, considerando sensibilidades típicas (2 mV/V a 3 mV/V) y estimando salidas de aproximadamente 10 mV a fondo de escala con excitación de 5 V.
\item Se definió la necesidad de implementar una etapa de acondicionamiento analógico que incluya amplificación, filtrado, offset y escalado antes de la digitalización.
\item Se analizó el sensor de temperatura real del motor, identificando que corresponde a un sistema PTC en serie utilizado para protección térmica, cuya salida es resistiva y no adecuada para medición continua.
\item Se propuso como mejora futura la incorporación de un sensor tipo Pt100, permitiendo una medición de temperatura más precisa mediante excitación de corriente y lectura diferencial.
\item Se evaluó el uso de cable RJ45/UTP como medio físico de interconexión, destacando el uso de pares trenzados para señales diferenciales y su impacto positivo en la inmunidad al ruido.
\item Se definieron criterios de diseño para la entrada de la PCB, incluyendo protección contra ESD, filtrado EMI y referencia de tierra adecuada.
\item Se dimensionó preliminarmente la ganancia del sistema de torque, estableciendo rangos de 500 a 1000 V/V para adaptar señales de milivoltios a niveles compatibles con el controlador.
\item Se identificaron integrados recomendables para el acondicionamiento, como amplificadores de instrumentación tipo INA333, INA826 y AD8426.
\item Se analizó la etapa de adquisición del sistema imperix BoomBox, comprendiendo su funcionamiento con ADC diferencial de 16 bits y lectura máxima considerada de hasta ±5 V.
\item Se estableció la importancia de diseñar la PCB de forma que la señal final quede dentro del rango del ADC, evitando saturación o activación de protecciones.
\end{itemize}

\textbf{Resultados:}
Se obtuvo una arquitectura completa y fundamentada del sistema, sirviendo como base sólida para el diseño de la PCB y la integración con el controlador.

\textbf{Dificultades:}
Integrar correctamente todos los bloques del sistema y validar supuestos de diseño sin contar aún con todos los datasheets definitivos.

% =========================
\subsection{Validación experimental de sensores de temperatura}
\textbf{Fecha:} 15/04/2026 \quad \textbf{Hora:} 14:00--18:30

\textbf{Objetivo:}
Verificar experimentalmente el tipo de sensor de temperatura presente en el motor mediante una visita al laboratorio LabCES.

\textbf{Desarrollo:}
\begin{itemize}
\item Se realizó una visita al laboratorio \textbf{LabCES} con el fin de inspeccionar directamente el motor y verificar la naturaleza de los sensores de temperatura instalados.
\item Se efectuó una inspección física del cableado del motor, identificando la presencia de tres grupos de conductores similares, cada uno compuesto por tres hilos.
\item Se planteó la hipótesis de que cada grupo correspondía a un sensor independiente asociado a cada fase del motor trifásico.
\item Se procedió a realizar mediciones de resistencia utilizando un multímetro en cada uno de los grupos.
\item Se obtuvieron valores en el rango de \SIrange{111}{112}{\ohm} de manera consistente en los tres conjuntos de conductores.
\item A partir de estos resultados, se descartó la hipótesis inicial de sensores tipo PTC y se identificó que los sensores corresponden a \textbf{RTD tipo Pt100 de 3 hilos}.
\item Se relacionaron los valores medidos con el comportamiento teórico del Pt100, el cual presenta una resistencia nominal de \SI{100}{\ohm} a \SI{0}{\celsius} y aumenta con la temperatura.
\end{itemize}

\textbf{Resultados:}
Se confirmó experimentalmente, durante la visita a LabCES, que el sistema de temperatura del motor está compuesto por \textbf{tres sensores Pt100 de 3 hilos}, uno por fase.

\textbf{Dificultades:}
Interpretación inicial del cableado y diferenciación entre sensores PTC y RTD.

% -------------------------

\subsection{Rediseño del sistema y ajuste de parámetros de adquisición}
\textbf{Fecha:} 17/04/2026 \quad \textbf{Hora:} 19:00--23:30

\textbf{Objetivo:}
Actualizar la arquitectura del sistema y definir parámetros de ganancia y margen de seguridad.

\textbf{Desarrollo:}
\begin{itemize}
\item Se actualizó el documento técnico del proyecto, incorporando la validación experimental de los sensores Pt100 y eliminando la referencia previa a sensores PTC.
\item Se redefinió la arquitectura del sistema, estableciendo tres canales independientes de temperatura y un canal de torque.
\item Se analizó el rango de salida del sistema de referencia imperix, identificando que el módulo ModuLink presenta una salida máxima aproximada de \(\pm 4.95\ \mathrm{V}\).
\item Se tomó la decisión de no operar al límite del sistema, sino de implementar un margen de seguridad del orden del \(5\%\), definiendo una tensión eléctrica máxima de diseño cercana a \SI{4.7}{V}.
\item Para el sensor de torque, se adoptó un valor de diseño intermedio de \SI{50}{mV}, dentro del rango típico de sensores tipo puente, y se calculó una ganancia aproximada de \(95\) a \(100\ \mathrm{V/V}\).
\item Para los sensores Pt100, considerando una señal aproximada de \SI{112}{mV} obtenida mediante excitación por corriente, se estimó una ganancia de \(40\) a \(42\ \mathrm{V/V}\).
\item Se reforzó la necesidad de amplificación mediante amplificadores de instrumentación para el canal de torque, debido a su baja amplitud y naturaleza diferencial.
\item Se estableció que el canal de temperatura requiere una etapa previa de conversión de resistencia a tensión eléctrica antes del acondicionamiento.
\item Se ajustaron las ecuaciones del sistema, los diagramas de bloques y la tabla de señales, logrando coherencia entre el diseño teórico y los resultados experimentales.
\end{itemize}

% ---- AQUÍ VA EL DIAGRAMA ----

\begin{figure}[H]
\centering
\begin{adjustbox}{max width=0.98\textwidth}
\begin{tikzpicture}[
node distance=0.65cm and 0.85cm,
block/.style={draw, rounded corners, align=center, minimum height=1.15cm, minimum width=2.8cm},
line/.style={-{Latex[length=2.2mm]}}
]

\node[block] (torque) {Sensor de torque\\(puente de Wheatstone)};
\node[block, below=of torque] (temp) {3 sensores Pt100\\(uno por fase)};

\node[block, right=of torque] (in1) {Protección\\y filtrado};
\node[block, right=of in1] (amp1) {Amplificación\\instrumental};
\node[block, right=of amp1] (drv1) {Driver\\diferencial};

\node[block, right=of temp] (r2v) {Excitación\\y conversión R$\rightarrow$V};
\node[block, right=of r2v] (amp2) {Amplificación\\y filtrado};
\node[block, right=of amp2] (drv2) {Driver\\diferencial};

\node[block, right=1.3cm of drv1, minimum width=3.6cm] (stp) {Cable STP / RJ45\\blindado};
\node[block, right=of stp, minimum width=3.7cm] (bbox) {BoomBox\\ADC diferencial};
\node[block, below=of bbox, minimum width=3.0cm] (ctrl) {FPGA / CPU\\control y monitoreo};

\draw[line] (torque) -- (in1);
\draw[line] (in1) -- (amp1);
\draw[line] (amp1) -- (drv1);
\draw[line] (temp) -- (r2v);
\draw[line] (r2v) -- (amp2);
\draw[line] (amp2) -- (drv2);

\draw[line] (drv1.east) -- ++(0.35,0) |- (stp.west);
\draw[line] (drv2.east) -- ++(0.35,0) |- (stp.west);

\draw[line] (stp) -- (bbox);
\draw[line] (bbox) -- (ctrl);

\end{tikzpicture}
\end{adjustbox}
\caption{Diagrama de bloques actualizado del sistema de adquisición, incorporando los tres sensores Pt100 y el acondicionamiento diferencial hacia BoomBox.}
\label{fig:bloques_semana6}
\end{figure}

% ---- FIN DIAGRAMA ----

\textbf{Resultados:}
Se obtuvo una versión actualizada y consistente del diseño, con parámetros de ganancia y márgenes de seguridad definidos y justificados.

\textbf{Dificultades:}
Definir valores de diseño balanceando resolución, ruido y saturación sin exceder el rango del sistema.

% =========================
\section{Sexta semana}

% -------------------------
\subsection{Análisis del sistema de adquisición y arquitectura general}
\textbf{Fecha:} 22/04/2026 \quad \textbf{Hora:} 18:00--20:30

\textbf{Objetivo:}
Comprender la arquitectura completa del sistema y definir el flujo de señal desde los sensores hasta la BoomBox.

\textbf{Desarrollo:}
\begin{itemize}
\item Se revisó la arquitectura general del sistema, identificando que la señal debe mantenerse analógica hasta la BoomBox.
\item Se corrigió la idea inicial de digitalización en la PCB, estableciendo que el ADC pertenece al sistema imperix.
\item Se definió el uso de señal diferencial como requisito fundamental para la transmisión.
\item Se estableció la cadena funcional sensor--PCB--BoomBox como base del diseño.
\end{itemize}

\textbf{Resultados:}
Se definió correctamente la arquitectura del sistema de adquisición.

\textbf{Dificultades:}
Diferenciar claramente entre acondicionamiento analógico y digitalización.

% -------------------------
\subsection{Análisis de sensores y cálculo de estimación de parámetros }
\textbf{Fecha:} 23/04/2026 \quad \textbf{Hora:} 19:00--22:00

\textbf{Objetivo:}
Analizar cómo se comportan eléctricamente los sensores y definir los valores básicos necesarios para el diseño.

\textbf{Desarrollo:}
\begin{itemize}
\item Se analizó el sensor de torque como un puente de Wheatstone, identificando su salida en el rango de milivolts.
\item Se estableció un valor de diseño de \SI{50}{mV} para el cálculo de ganancia.
\item Se analizaron los sensores Pt100, confirmando su comportamiento resistivo y la necesidad de excitación por corriente.
\item Se definió una corriente de excitación de \SI{1}{mA} para los sensores de temperatura.
\item Se calcularon las señales esperadas en los sensores, obteniendo valores del orden de \SIrange{100}{112}{mV}.
\end{itemize}

\textbf{Resultados:}
Se definieron los rangos eléctricos de entrada del sistema.

\textbf{Dificultades:}
Ajustar valores sin contar aún con todos los datasheets definitivos.

% -------------------------
\subsection{Definición de etapas de amplificación y filtrado}
\textbf{Fecha:} 23/04/2026 \quad \textbf{Hora:} 22:00--23:30

\textbf{Objetivo:}
Definir las etapas de amplificación y la estrategia de filtrado del sistema.

\textbf{Desarrollo:}
\begin{itemize}
\item Se estableció el uso de amplificadores de instrumentación para la lectura del sensor de torque.
\item Se definieron ganancias aproximadas de \(G \approx 100\) para torque y \(G \approx 40\) para temperatura.
\item Se analizó el uso de amplificadores operacionales auxiliares para etapas de filtrado y ajuste.
\item Se propuso la implementación de un filtro pasabajo ajustable mediante trimmer.
\item Se definió un rango preliminar de frecuencia de corte para validación experimental.
\end{itemize}

\textbf{Resultados:}
Se establecieron las bases del acondicionamiento analógico.

\textbf{Dificultades:}
Determinar la frecuencia de corte sin mediciones reales de ruido.

% -------------------------
\subsection{Definición final del esquema de acondicionamiento y bloques de la PCB}
\textbf{Fecha:} 24/04/2026 \quad \textbf{Hora:} 17:00--23:00

\textbf{Objetivo:}
Consolidar el diseño del esquema eléctrico preliminar de la PCB, integrando todos los bloques funcionales, valores de diseño y criterios de ingeniería definidos durante la semana.

\textbf{Desarrollo:}
\begin{itemize}
\item Se realizó una revisión completa del sistema de acondicionamiento, integrando la información obtenida sobre los sensores de torque y temperatura en una única arquitectura coherente.
\item Se definió formalmente la cadena de procesamiento de señal desde los sensores hasta la BoomBox, estableciendo las etapas: protección, amplificación instrumental, filtrado, ajuste de escala y salida diferencial.
\item Se adoptó un valor de diseño de \SI{50}{mV} para el sensor de torque y se definió una ganancia aproximada de \(G \approx 100\).
\item Para los sensores Pt100, se estableció una corriente de excitación de \SI{1}{mA} y una ganancia aproximada de \(G \approx 40\).
\item Se definió la inclusión de un filtro pasabajo ajustable mediante trimmer para validar experimentalmente el ruido del sistema.
\item Se estableció el uso de señal diferencial en la salida de la PCB y cable STP con conector RJ45 como medio físico.
\item Se definieron criterios de alimentación mediante fuente externa \(V_{dc}\), con consumo estimado entre \SIrange{30}{70}{mA}.
\item Se incorporaron elementos de protección y desacoplo para robustecer la PCB.
\end{itemize}

\textbf{Resultados:}
Se obtuvo una definición clara, coherente y fundamentada del esquema eléctrico de la PCB.

\textbf{Dificultades:}
Definir valores de diseño sin mediciones completas del entorno real.

\section{Séptima semana}

% -------------------------
\subsection{Validación de parámetros eléctricos mediante hojas de datos}
\textbf{Fecha:} 29/04/2026 \quad \textbf{Hora:} 18:00--22:00

\textbf{Objetivo:}
Verificar los valores eléctricos reales de los sensores y ajustar los parámetros de diseño con base en información técnica confiable.

\textbf{Desarrollo:}
\begin{itemize}
\item Se revisaron hojas de datos del sensor de torque tipo puente Wheatstone, confirmando una impedancia de entrada y salida cercana a \SI{350}{\ohm}.
\item Se validó una excitación recomendada de \SI{10}{V}, con una sensibilidad aproximada de \SI{3}{mV/V}.
\item Se determinó que la salida máxima del sensor es del orden de \SIrange{1}{30}{mV}, consistente con sensores de este tipo \cite{InterfaceSM50}.
\item Se analizaron las características de precisión del sensor, observando bajo error de cero, baja no linealidad y baja histéresis.
\item Se confirmó que los sensores de temperatura corresponden a tipo Pt100, basado en mediciones experimentales realizadas en laboratorio.
\item Se verificó el comportamiento resistivo del Pt100, con valores de \SI{100}{\ohm} a \SI{0}{^\circ C} y aproximadamente \SI{138.5}{\ohm} a \SI{100}{^\circ C}.
\item Se validó el uso de una corriente de excitación de \SI{1}{mA}, obteniendo señales en el rango de \SIrange{100}{138}{mV}.
\end{itemize}

\textbf{Resultados:}
Se obtuvieron valores eléctricos reales y confiables para ambos sensores, permitiendo validar el diseño del sistema.

\textbf{Dificultades:}
Falta de identificación directa del sensor de temperatura, lo que requirió validación experimental.

% -------------------------
\subsection{Análisis del acondicionamiento mediante puente Wheatstone}
\textbf{Fecha:} 29/04/2026 \quad \textbf{Hora:} 22:00--23:30

\textbf{Objetivo:}
Definir la estrategia de obtención de señal para sensores resistivos y su integración en el sistema.

\textbf{Desarrollo:}
\begin{itemize}
\item Se analizó el funcionamiento del puente Wheatstone como método de medición diferencial para sensores resistivos.
\item Se estableció que el sensor de torque ya integra un puente completo, mientras que el Pt100 requiere configuración externa.
\item Se definió que la señal útil es la diferencia entre las salidas del puente, la cual es proporcional a la variación de resistencia.
\item Se identificó que las señales obtenidas son del orden de \SIrange{1}{30}{mV}, requiriendo amplificación.
\item Se reafirmó el uso de amplificadores de instrumentación debido a su alta impedancia de entrada y rechazo de modo común .
\end{itemize}

\textbf{Resultados:}
Se definió correctamente la forma de obtención de señal para ambos sensores.

\textbf{Dificultades:}
Comprender el impacto del modo común en la medición diferencial.

% -------------------------
\subsection{Revisión con el profesor y validación de salidas del sistema}
\textbf{Fecha:} 30/04/2026 \quad \textbf{Hora:} 20:00--23:00

\textbf{Objetivo:}
Validar con el profesor los niveles de salida del sistema y confirmar la viabilidad del diseño.

\textbf{Desarrollo:}
\begin{itemize}
\item Se presentó al profesor el análisis realizado de los sensores y sus parámetros eléctricos.
\item Se discutieron los niveles de señal obtenidos y su compatibilidad con la etapa de adquisición (BoomBox).
\item Se validaron formalmente los niveles de salida definidos, respaldados por hojas de datos.
\item Se recibió retroalimentación sobre la importancia del manejo diferencial de la señal.
\item Se discutieron criterios de robustez frente a ruido en el entorno industrial del motor.
\item El profesor proporcionó material bibliográfico sobre diseño de sistemas de acondicionamiento de señal para fortalecer la base teórica del proyecto.
\end{itemize}

\textbf{Resultados:}
Se validaron los niveles de salida del sistema y se confirmó la coherencia del diseño propuesto.

\textbf{Dificultades:}
Ajustar el diseño considerando restricciones reales del sistema de adquisición.

% -------------------------
\subsection{Integración final de parámetros y ajustes del diseño}
\textbf{Fecha:} 30/04/2026 \quad \textbf{Hora:} 17:00--18:30

\textbf{Objetivo:}
Integrar todos los parámetros validados en el diseño del sistema de acondicionamiento.

\textbf{Desarrollo:}
\begin{itemize}
\item Se ajustaron los valores de ganancia en función de los datos reales obtenidos.
\item Se consolidó el uso de \(G \approx 100\) para torque y \(G \approx 40\) para temperatura.
\item Se verificó la coherencia entre los niveles de entrada y salida del sistema.
\item Se integraron los criterios de diseño en la arquitectura general de la PCB.
\item Se dejaron definidos los parámetros base para la siguiente etapa de diseño esquemático en KiCad.
\end{itemize}

\textbf{Resultados:}
Se obtuvo un diseño ajustado y validado con base en datos reales y criterio técnico.

\textbf{Dificultades:}
Ajustar todos los parámetros manteniendo compatibilidad con el sistema completo.

% =========================
\section{Octava semana}

% -------------------------
\subsection{Revisión de avances y organización de la bitácora}
\textbf{Fecha:} 05/05/2026 \quad \textbf{Hora:} 18:00--21:00

\textbf{Objetivo:}
Ordenar los avances acumulados del proyecto y dejar documentadas las decisiones técnicas tomadas hasta el momento.

\textbf{Desarrollo:}
\begin{itemize}
\item Se revisó el avance general de la bitácora para verificar que las semanas anteriores mantuvieran una estructura uniforme.
\item Se reorganizó la información relacionada con la arquitectura del sistema de acondicionamiento.
\item Se reforzó la idea de mantener la señal analógica desde los sensores hasta la etapa de adquisición del sistema BoomBox.
\item Se revisaron nuevamente los bloques principales del sistema: sensor, protección, amplificación, filtrado, ajuste de escala y salida diferencial.
\item Se corrigió la redacción técnica del documento para usar términos más adecuados, como tensión eléctrica, volts y milivolts.
\item Se identificaron puntos que aún requerían justificación con hojas de datos y material técnico.
\end{itemize}

\textbf{Resultados:}
Se dejó más ordenada la documentación del proyecto y se aclararon las decisiones principales de la arquitectura de la PCB.

\textbf{Dificultades:}
Mantener la bitácora clara sin perder información técnica importante del proyecto.

% -------------------------
\subsection{Revisión de criterios para el acondicionamiento de señales}
\textbf{Fecha:} 10/05/2026 \quad \textbf{Hora:} 19:00--22:30

\textbf{Objetivo:}
Reforzar la base teórica necesaria para el diseño de la PCB mediante la revisión de conceptos de sensores y acondicionamiento de señal.

\textbf{Desarrollo:}
\begin{itemize}
\item Se inició una revisión guiada del libro de sensores y acondicionadores de señal, enfocándose en los temas más relacionados con el proyecto.
\item Se identificaron conceptos importantes como sensibilidad, rango dinámico, ganancia, offset, resolución e incertidumbre.
\item Se relacionaron estos conceptos con las señales esperadas en el sensor de torque y en los sensores de temperatura.
\item Se analizó la necesidad de adaptar señales pequeñas, del orden de milivolts, hacia niveles compatibles con la adquisición.
\item Se repasó la importancia de evitar saturación en las etapas analógicas y de dejar margen suficiente en el rango de salida.
\item Se anotaron fórmulas base para continuar con los cálculos de ganancia y escalamiento durante la siguiente semana.
\end{itemize}

\textbf{Resultados:}
Se reforzó la teoría necesaria para justificar el diseño del acondicionamiento y se identificaron las fórmulas principales para el análisis de señales.

\textbf{Dificultades:}
Distinguir cuándo una tensión corresponde al valor mínimo, máximo, offset o fondo de escala del sistema.

% =========================
\section{Novena semana}

% -------------------------
\subsection{Estudio de rango dinámico, offset y resolución del ADC}
\textbf{Fecha:} 13/05/2026 \quad \textbf{Hora:} 16:00--19:00

\textbf{Objetivo:}
Comprender cómo se relacionan la señal del sensor, la ganancia, el offset y la resolución del ADC dentro del sistema de adquisición.

\textbf{Desarrollo:}
\begin{itemize}
\item Se estudiaron problemas del libro relacionados con rango dinámico, resolución y acondicionamiento de señales.
\item Se revisó el significado de términos como fondo de escala, valor mínimo, valor máximo, offset y número de bits.
\item Se analizó cómo una señal pequeña del sensor puede ocupar solo una parte del rango del ADC si no se amplifica correctamente.
\item Se revisó la expresión del efecto del offset en una cadena de medición, considerando resistencia de salida, corriente de entrada y ganancia.
\item Se estudió cómo una tensión de offset amplificada puede reducir el número efectivo de bits disponibles para representar la señal útil.
\item Se relacionó este análisis con el diseño del acondicionamiento para torque y temperatura.
\end{itemize}

\textbf{Resultados:}
Se comprendió mejor la función del offset y su impacto sobre la resolución efectiva del sistema de adquisición.

\textbf{Dificultades:}
Interpretar correctamente si una tensión dada representa el valor mínimo, el offset o el valor máximo esperado del sensor.

% -------------------------
\subsection{Análisis de fórmulas para puente Wheatstone y señal diferencial}
\textbf{Fecha:} 14/05/2026 \quad \textbf{Hora:} 18:00--21:30

\textbf{Objetivo:}
Revisar las ecuaciones necesarias para analizar un puente Wheatstone aplicado a sensores resistivos.

\textbf{Desarrollo:}
\begin{itemize}
\item Se repasó el funcionamiento general del puente Wheatstone como estructura de medición para sensores resistivos.
\item Se revisó que, cuando el puente está balanceado, la salida diferencial ideal es cercana a cero.
\item Se analizó que una variación de resistencia en los brazos del puente produce una tensión diferencial proporcional al cambio físico medido.
\item Se relacionó el puente Wheatstone con el sensor de torque, debido a que este tipo de sensor entrega una señal diferencial de baja amplitud.
\item Se reforzó la necesidad de usar un amplificador de instrumentación para medir la diferencia entre las salidas del puente y rechazar la tensión de modo común.
\item Se revisó la importancia de que la etapa de entrada tenga alta impedancia para no cargar el puente ni alterar la medición.
\end{itemize}

\textbf{Resultados:}
Se aclaró la relación entre puente Wheatstone, señal diferencial, modo común y amplificación instrumental.

\textbf{Dificultades:}
Diferenciar entre la tensión diferencial útil del puente y la tensión de modo común presente en sus nodos de salida.

% -------------------------
\subsection{Consolidación de fórmulas y criterios para el diseño de la PCB}
\textbf{Fecha:} 15/05/2026 \quad \textbf{Hora:} 17:00--20:00

\textbf{Objetivo:}
Consolidar las fórmulas y criterios técnicos necesarios para continuar con el diseño esquemático de la PCB.

\textbf{Desarrollo:}
\begin{itemize}
\item Se organizaron las fórmulas principales relacionadas con sensibilidad, ganancia, offset, rango dinámico y resolución del ADC.
\item Se revisó cómo nombrar correctamente las variables para evitar confusiones al aplicar las ecuaciones.
\item Se relacionaron las fórmulas del libro con el caso práctico del proyecto de sensores de torque y temperatura.
\item Se identificó que el diseño debe mantener margen de salida para evitar saturación frente a offset, ruido o variaciones reales del sensor.
\item Se reforzó la idea de que el acondicionamiento debe incluir protección, amplificación, filtrado y salida diferencial.
\item Se dejaron definidos los puntos teóricos que deben revisarse antes de avanzar con el esquemático final en KiCad.
\end{itemize}

\textbf{Resultados:}
Se obtuvo una base de fórmulas más clara para continuar el diseño de la PCB con mejor criterio técnico.

\textbf{Dificultades:}
Ordenar las fórmulas de forma que sean útiles para resolver problemas y, al mismo tiempo, aplicables al diseño real del proyecto.

% =========================
\section{Décima semana}

% -------------------------
\subsection{Validación de datos reales del sensor SM-50}
\textbf{Fecha:} 19/05/2026 \quad \textbf{Hora:} 10:00--14:00

\textbf{Objetivo:}
Corregir los datos del sensor de torque a partir de la información real de la hoja técnica del SM-50.

\textbf{Desarrollo:}
\begin{itemize}
\item Se revisó nuevamente la información del sensor Interface SM-50 para evitar trabajar con valores genéricos o supuestos incorrectos.
\item Se corrigió la capacidad utilizada en el proyecto, tomando como referencia el valor real de \SI{20}{in.lb}, equivalente aproximadamente a \SI{2.2}{N.m}.
\item Se confirmó que la salida nominal del sensor es de \SI{3.0}{mV/V}, por lo que con una excitación de \SI{10}{V} se obtiene una señal diferencial máxima cercana a \SI{30}{mV}.
\item Se registraron parámetros importantes para la defensa técnica: resistencia nominal del puente de \SI{350}{\ohm}, no linealidad de \SI{\pm 0.03}{\percent} FS, histéresis de \SI{\pm 0.02}{\percent} FS y balance de cero de \SI{\pm 1}{\percent} RO.
\item Se corrigió la interpretación del cableado del sensor, dejando como referencia: rojo para +EXC, negro para -EXC, verde para +OUT, blanco para -OUT y blindaje para SHIELD.
\end{itemize}

\textbf{Resultados:}
Se obtuvo una base de datos real para el canal de torque, eliminando el error de trabajar con rangos de torque que no correspondían al sensor seleccionado.

\textbf{Dificultades:}
Distinguir entre valores típicos de sensores de puente y los valores específicos del SM-50 que realmente se usarán en el proyecto.

% -------------------------
\subsection{Corrección e integración del documento técnico del proyecto}
\textbf{Fecha:} 22/05/2026 \quad \textbf{Hora:} 19:00--23:30

\textbf{Objetivo:}
Unificar la información técnica del proyecto en un solo documento base y corregir errores de formato en LaTeX.

\textbf{Desarrollo:}
\begin{itemize}
\item Se revisaron documentos anteriores del proyecto para unir la información de sensores, acondicionamiento, alimentación, conectores y criterios de PCB.
\item Se depuró la estructura del documento principal, separando la información por bloques funcionales para facilitar su lectura.
\item Se corrigieron errores de compilación y de descarga del archivo, priorizando que el documento pudiera exportarse correctamente.
\item Se organizó una guía de continuación del proyecto, indicando qué partes faltaban por cerrar antes de pasar al esquemático definitivo.
\item Se reforzó que el diseño debe documentar no solo los cálculos, sino también las razones técnicas de cada decisión.
\end{itemize}

\textbf{Resultados:}
Se obtuvo una versión más ordenada del documento técnico del proyecto, lista para seguir siendo completada con los valores definitivos.

\textbf{Dificultades:}
La principal dificultad fue mantener toda la información en un solo archivo sin perder coherencia ni generar errores de compilación.

% -------------------------
\subsection{Actualización de tablas de sensores y criterios de acondicionamiento}
\textbf{Fecha:} 23/05/2026 \quad \textbf{Hora:} 10:00--15:00

\textbf{Objetivo:}
Actualizar las tablas del proyecto con datos más claros para el PT100 y el SM-50.

\textbf{Desarrollo:}
\begin{itemize}
\item Se actualizó la tabla de caracterización de sensores con los datos corregidos del SM-50 y del PT100.
\item Para el PT100 se reforzó el uso de una corriente de excitación de \SI{1}{mA}, debido a que permite convertir la resistencia del sensor en una tensión medible con bajo autocalentamiento.
\item Para el sensor de torque se mantuvo el criterio de puente resistivo con salida diferencial de baja amplitud, por lo que se requiere amplificación instrumental.
\item Se incluyeron recomendaciones prácticas de desacoplo, como capacitores de \SI{100}{nF} cercanos a los circuitos integrados y capacitores de mayor valor por zona de alimentación.
\item Se ajustó el lenguaje de las recomendaciones para que quedara más claro y defendible en una presentación oral.
\end{itemize}

\textbf{Resultados:}
Las tablas quedaron más alineadas con los sensores reales y con las necesidades de acondicionamiento de la PCB.

\textbf{Dificultades:}
Evitar que la tabla mezclara datos de cálculo preliminar con valores ya corregidos o confirmados por hoja técnica.

% =========================
\section{Undécima semana}

% -------------------------
\subsection{Memoria de cálculo del canal PT100 y del canal de torque}
\textbf{Fecha:} 27/05/2026 \quad \textbf{Hora:} 00:30--04:30

\textbf{Objetivo:}
Construir una memoria de cálculo para justificar la ganancia, sensibilidad y resolución de los dos canales de medición.

\textbf{Desarrollo:}
\begin{itemize}
\item Se desarrolló el modelo lineal del PT100 usando \(R_0=\SI{100}{\ohm}\) y una sensibilidad aproximada de \SI{0.385}{\ohm/\celsius}.
\item Se calculó que, con \SI{1}{mA} de excitación, el PT100 entrega aproximadamente \SI{100}{mV} a \SI{0}{\celsius} y \SI{138.5}{mV} a \SI{100}{\celsius}.
\item Se identificó que los \SI{100}{mV} iniciales corresponden a offset y que la información útil del rango de \SI{0}{\celsius} a \SI{100}{\celsius} está en la variación de \SI{38.5}{mV}.
\item Se calculó una ganancia corregida cercana a \(G\approx 86\) para usar el rango útil después de restar el offset.
\item Para torque se calculó que la sensibilidad del puente, con \SI{10}{V} de excitación y \SI{3}{mV/V}, produce una salida máxima cercana a \SI{30}{mV}.
\item Se verificó que la ganancia final del canal SM-50, \(G\approx 146.29\) con \(R_G=\SI{340}{\ohm}\), permite llevar la señal del puente a una salida bipolar nominal de \(\pm\SI{4.39}{V}\) sin saturar la entrada de la BoomBox.
\end{itemize}

\textbf{Resultados:}
Se estableció una memoria de cálculo base para defender por qué el PT100 y el SM-50 requieren etapas de amplificación distintas.

\textbf{Dificultades:}
La dificultad principal fue separar correctamente el offset del PT100 de la señal útil de temperatura para no calcular una ganancia incorrecta.

% -------------------------
\subsection{Verificación de resolución y criterio de bits del sistema de adquisición}
\textbf{Fecha:} 27/05/2026 \quad \textbf{Hora:} 12:00--15:00

\textbf{Objetivo:}
Aclarar el papel del número de bits del sistema de adquisición en el proyecto.

\textbf{Desarrollo:}
\begin{itemize}
\item Se revisó que el número de bits no se estaba usando para seleccionar un ADC externo, ya que la digitalización final la realiza el sistema BoomBox.
\item Se interpretó el cálculo de bits como una verificación de resolución, no como una etapa de selección de convertidor.
\item Se reforzó que el diseño analógico debe entregar una señal limpia, escalada y compatible con el rango de entrada del sistema de adquisición.
\item Se aclaró que el objetivo es comprobar si la resolución disponible del sistema es suficiente para leer los cambios de torque y temperatura sin perder información importante.
\item Se relacionó esta verificación con el rango de salida del acondicionamiento, evitando usar ganancias excesivas solo por intentar llenar todo el rango de conversión.
\end{itemize}

\textbf{Resultados:}
Se aclaró que el cálculo de bits funciona como una comprobación de coherencia del diseño y no como una selección de hardware adicional.

\textbf{Dificultades:}
Diferenciar entre diseñar un ADC propio y acondicionar señales para un sistema de adquisición que ya posee su propia etapa de digitalización.

% -------------------------
\subsection{Selección preliminar de componentes de acondicionamiento}
\textbf{Fecha:} 27/05/2026 \quad \textbf{Hora:} 18:00--21:30

\textbf{Objetivo:}
Comparar opciones de amplificadores de instrumentación y operacionales para justificar la selección de componentes.

\textbf{Desarrollo:}
\begin{itemize}
\item Se compararon amplificadores de instrumentación adecuados para señales diferenciales pequeñas, dando prioridad a CMRR, offset, deriva, facilidad de ajuste de ganancia y disponibilidad.
\item Se revisó el uso del INA828 como opción principal por su precisión y por ser adecuado para señales de bajo nivel provenientes de sensores de puente y RTD.
\item Se analizaron alternativas de menor costo o más accesibles, como INA826 o AD620, para tener opciones defendibles si cambia la disponibilidad de componentes.
\item Se revisó el papel de amplificadores operacionales como LF353, entendiendo que no sustituyen directamente a un amplificador de instrumentación para la primera etapa de medida diferencial.
\item Se separó la comparación en dos familias: amplificadores de instrumentación para la extracción diferencial y operacionales para filtrado, buffer, offset o etapas auxiliares.
\end{itemize}

\textbf{Resultados:}
Se definió que la primera etapa crítica debe ser un amplificador de instrumentación, mientras que los operacionales quedan como apoyo para filtros, referencias o adaptación de salida.

\textbf{Dificultades:}
Evitar comparar directamente componentes que cumplen funciones distintas dentro de la cadena analógica.

% -------------------------
\subsection{Revisión de documentación imperix y naturaleza de la salida hacia BoomBox}
\textbf{Fecha:} 28/05/2026 \quad \textbf{Hora:} 13:00--15:00

\textbf{Objetivo:}
Aclarar cómo debe conectarse la PCB al ecosistema imperix BoomBox.

\textbf{Desarrollo:}
\begin{itemize}
\item Se revisó documentación relacionada con módulos imperix para entender la filosofía de entrada y salida analógica por conectores tipo RJ45.
\item Se corrigió la idea de que el enlace hacia la BoomBox fuese digital o por fibra en esta etapa; la salida de la PCB se mantiene como señal analógica acondicionada.
\item Se adoptó como criterio que la señal hacia la BoomBox debe ser diferencial, balanceada y transportada por cable STP/RJ45.
\item Se identificó que la BoomBox es la encargada de realizar la digitalización, por lo que la PCB debe concentrarse en protección, acondicionamiento, filtrado y adaptación de rango.
\item Se revisó que la salida debe mantenerse dentro de un margen seguro, evitando saturación del frente analógico de entrada.
\end{itemize}

\textbf{Resultados:}
Se corrigió la arquitectura de comunicación: sensor, PCB propia, salida analógica diferencial por STP/RJ45 y entrada analógica de la BoomBox.

\textbf{Dificultades:}
Interpretar correctamente el uso físico del RJ45, ya que no se trata de Ethernet sino de un conector multipar para señales analógicas y alimentación.

% =========================
\section{Duodécima semana}

% -------------------------
\subsection{Revisión de alimentación para pruebas y protoboard}
\textbf{Fecha:} 31/05/2026 \quad \textbf{Hora:} 16:00--18:00

\textbf{Objetivo:}
Definir la forma más recomendable de alimentar el circuito durante pruebas y en la versión final.

\textbf{Desarrollo:}
\begin{itemize}
\item Se revisó que el circuito requiere rieles de alimentación compatibles con etapas analógicas, principalmente \(\pm\SI{15}{V}\) para permitir margen de operación.
\item Se diferenció la alimentación de pruebas en protoboard de la alimentación final de la PCB.
\item Se reforzó que la protoboard puede servir para validar funciones básicas, pero no es una prueba definitiva de ruido debido a capacitancias parásitas, falta de plano de tierra y conexiones largas.
\item Se revisó que la alimentación final no debe provenir de los sensores, sino del sistema de adquisición o de la interfaz definida para la tarjeta.
\item Se consideró la necesidad de desacoplo local por circuito integrado y distribución ordenada de los rieles dentro de la PCB.
\end{itemize}

\textbf{Resultados:}
Se estableció que las pruebas pueden hacerse con fuente de laboratorio, pero el diseño final debe considerar alimentación estable, desacoplada y correctamente distribuida.

\textbf{Dificultades:}
Separar lo que es válido para una prueba rápida en protoboard de lo que debe cumplir una PCB final cercana a un motor e inversor.

% -------------------------
\subsection{Comparación técnica de etapas diferenciales e instrumentales}
\textbf{Fecha:} 31/05/2026 \quad \textbf{Hora:} 20:00--23:30

\textbf{Objetivo:}
Comparar técnicamente amplificadores diferenciales y de instrumentación para cerrar la arquitectura del acondicionamiento.

\textbf{Desarrollo:}
\begin{itemize}
\item Se revisaron fuentes técnicas sobre acondicionamiento de puentes Wheatstone y medición de señales diferenciales de baja amplitud.
\item Se comparó el uso de un amplificador diferencial con resistencias externas frente a un amplificador de instrumentación integrado.
\item Se identificó que el amplificador diferencial exige resistencias muy bien apareadas para mantener buen rechazo de modo común.
\item Se concluyó que el amplificador de instrumentación es más robusto para la primera etapa porque ofrece alta impedancia de entrada y alto CMRR.
\item Se dejó el operacional diferencial como opción para etapas posteriores, como adaptación de salida, offset, filtrado activo o conversión diferencial si se requiere.
\end{itemize}

\textbf{Resultados:}
Se fortaleció la decisión de usar un INA como primera etapa para torque y temperatura, dejando los operacionales como bloques auxiliares.

\textbf{Dificultades:}
Defender por qué dos circuitos que parecen similares en esquema no se comportan igual frente a modo común, tolerancias y ruido.

% -------------------------
\subsection{Definición de conectores del SM-50 y salidas RJ45}
\textbf{Fecha:} 01/06/2026 \quad \textbf{Hora:} 02:00--05:00

\textbf{Objetivo:}
Definir conectores prácticos para el sensor SM-50 y para la interfaz de la PCB con la BoomBox.

\textbf{Desarrollo:}
\begin{itemize}
\item Se revisó el conector físico del sensor SM-50 y la necesidad de adaptar sus líneas hacia una entrada robusta en PCB.
\item Se propuso usar una bornera push-in de 5 pines para recibir +EXC, -EXC, +SIG, -SIG y SHIELD.
\item Se planteó un arnés adaptador desde el conector del sensor hacia ferrules y bornera, evitando modificar el cable original del sensor.
\item Se definió que la salida hacia la BoomBox debe usar conectores RJ45 blindados, uno para torque y otro para temperatura.
\item Se estableció que la pantalla del RJ45 debe tratarse como blindaje o chasis, no como una conexión directa e indiscriminada al GND analógico.
\end{itemize}

\textbf{Resultados:}
Se obtuvo una propuesta práctica de conectores: entrada SM-50 por bornera de 5 pines y salida hacia BoomBox por RJ45 blindado.

\textbf{Dificultades:}
Elegir conectores que fueran fáciles de probar en laboratorio pero suficientemente robustos para una PCB real.

% -------------------------
\subsection{Organización de la PCB por ciudades funcionales}
\textbf{Fecha:} 01/06/2026 \quad \textbf{Hora:} 20:00--23:30

\textbf{Objetivo:}
Organizar físicamente la PCB por bloques o ciudades para reducir ruido y facilitar el diseño.

\textbf{Desarrollo:}
\begin{itemize}
\item Se definió una organización por ciudades para separar físicamente las zonas sensibles, la alimentación y las salidas.
\item La ciudad 1 corresponde a la entrada del SM-50, excitación del puente y filtro inicial.
\item La ciudad 2 corresponde al acondicionamiento de torque mediante INA, ajuste de ganancia y filtrado.
\item La ciudad 3 corresponde a la entrada del PT100 mediante bornera de 4 hilos, fuente de corriente y líneas de sense.
\item La ciudad 4 corresponde al acondicionamiento de temperatura, resta de offset, ganancia y filtrado.
\item La ciudad 5 corresponde a la alimentación desde la BoomBox, protección y desacoplo.
\item La ciudad 6 corresponde a las salidas RJ45 hacia la BoomBox para torque y temperatura.
\end{itemize}

\textbf{Resultados:}
Se obtuvo una distribución funcional que permite diseñar el esquemático y el layout con mejor control del ruido.

\textbf{Dificultades:}
Evitar mezclar físicamente señales de milivoltios con alimentación, conectores de salida y posibles retornos ruidosos.

% -------------------------
\subsection{Ajuste de alimentación final desde B-Box y referencia de \SI{3.3}{V}}
\textbf{Fecha:} 02/06/2026 \quad \textbf{Hora:} 13:00--18:00

\textbf{Objetivo:}
Cerrar la estrategia de alimentación de la PCB y justificar el uso de rieles internos auxiliares.

\textbf{Desarrollo:}
\begin{itemize}
\item Se revisó que la PCB no usará una fuente externa como alimentación principal, sino los rieles disponibles desde la B-Box por medio de los puertos analógicos RJ45.
\item Se definió que los rieles principales de entrada serán \( +\SI{15}{V} \), \( -\SI{15}{V} \) y GND, distribuidos por los conectores RJ45.
\item Se analizó que algunas etapas analógicas pueden trabajar directamente con rieles cercanos a \(\pm\SI{15}{V}\), mientras que referencias internas o bloques auxiliares pueden requerir \SI{3.3}{V}.
\item Se revisó el concepto de LDO como regulador lineal de baja caída para obtener una referencia o alimentación auxiliar limpia de \SI{3.3}{V}.
\item Se consideró la corriente disponible aproximada de \SI{100}{mA}, por lo que el consumo de referencias, INAs, operacionales y excitaciones debe mantenerse bajo control.
\item Se reforzó que la salida final debe aprovechar el rango permitido por la BoomBox sin sacrificar margen frente a saturación.
\end{itemize}

\textbf{Resultados:}
Se definió una arquitectura de alimentación más coherente: entrada \(\pm\SI{15}{V}\) desde B-Box, regulación local cuando haga falta y desacoplo por bloques.

\textbf{Dificultades:}
Distinguir entre alimentación principal, referencia de medición, excitación de sensores y niveles internos auxiliares.

% -------------------------
\subsection{Diseño conceptual de excitación para PT100 de tres hilos}
\textbf{Fecha:} 03/06/2026 \quad \textbf{Hora:} 15:30--20:30

\textbf{Objetivo:}
Definir una forma más segura y precisa de excitar el PT100 usando \SI{1}{mA}.

\textbf{Desarrollo:}
\begin{itemize}
\item Se revisó el uso de PT100 de tres hilos para compensar la resistencia de los cables cuando el sensor se encuentra separado de la PCB.
\item Se comparó la opción de una fuente de corriente hecha con amplificador operacional y transistor frente al uso de un circuito integrado de corriente de precisión.
\item Se identificó que una solución integrada, como REF200 o una fuente de corriente dedicada, reduce el riesgo de errores de implementación frente a una etapa discreta con LM358 y transistor.
\item Se mantuvo el criterio de \SI{1}{mA} como corriente de excitación para obtener una señal medible y reducir el autocalentamiento.
\item Se revisó que la tensión del PT100 debe medirse de forma diferencial y que el offset de \SI{100}{mV} a \SI{0}{\celsius} debe tratarse con cuidado antes de aplicar alta ganancia.
\item Se reforzó que el ajuste de calibración debe realizarse con trimmer cuando sea necesario, no con un potenciómetro de panel como elemento principal del diseño.
\end{itemize}

\textbf{Resultados:}
Se orientó el canal PT100 hacia una fuente de corriente más precisa y menos propensa a fallos, manteniendo la medición diferencial y la compensación de cableado.

\textbf{Dificultades:}
Elegir una arquitectura que sea precisa, fácil de defender y al mismo tiempo tenga baja probabilidad de fallar en la implementación física.

% =========================
\section{Decimotercera semana}

% -------------------------
\subsection{Revisión de documentación tipo handbook para esquemáticos de PCB}
\textbf{Fecha:} 07/06/2026 \quad \textbf{Hora:} 17:30--19:00

\textbf{Objetivo:}
Buscar referencias de diseño esquemático para orientar la presentación del circuito final.

\textbf{Desarrollo:}
\begin{itemize}
\item Se revisó la necesidad de usar ejemplos tipo handbook o notas de aplicación para que el esquemático no dependa únicamente de criterio propio.
\item Se identificaron fuentes útiles de fabricantes y notas de aplicación para puentes resistivos, RTD, acondicionamiento de señal y diseño de PCB.
\item Se relacionaron esas fuentes con los bloques del proyecto: excitación, protección, amplificación instrumental, filtrado, referencias y salida diferencial.
\item Se priorizó usar esquemas de aplicación como guía conceptual, adaptándolos a los sensores reales y al ecosistema BoomBox.
\end{itemize}

\textbf{Resultados:}
Se reforzó la estrategia de respaldar el diseño con circuitos de referencia y no solo con cálculos aislados.

\textbf{Dificultades:}
Encontrar ejemplos que sean parecidos al proyecto sin copiar una aplicación que no coincida con los rangos, sensores o alimentación disponibles.

% -------------------------
\subsection{Cierre de arquitectura final para PT100 y SM-50}
\textbf{Fecha:} 07/06/2026 \quad \textbf{Hora:} 19:30--22:30

\textbf{Objetivo:}
Actualizar la arquitectura final del informe considerando las últimas decisiones del proyecto.

\textbf{Desarrollo:}
\begin{itemize}
\item Se consolidó la arquitectura final separando claramente el canal PT100 y el canal SM-50.
\item Para el canal PT100 se decidió priorizar una fuente de corriente de precisión de \SI{1}{mA}, medición diferencial, resta de offset, ganancia moderada y filtrado pasabajo.
\item Se revisó la posibilidad de eliminar una fuente de corriente discreta con LM358 y transistor cuando una fuente integrada ofrezca mayor precisión y menor riesgo de error práctico.
\item Para el canal SM-50 se mantuvo la excitación del puente con referencia estable de \SI{10}{V}, lectura diferencial del puente, amplificación instrumental y filtrado.
\item Se corrigió la idea de usar potenciómetro, dejando claro que el ajuste físico adecuado en la PCB debe ser mediante trimmer multivuelta si se requiere calibración fina.
\item Se reforzó que el informe final debe distinguir entre alimentación de la PCB, excitación de sensores, referencia de offset, ganancia del INA y salida hacia la BoomBox.
\item Se agregó como criterio final que la PCB debe ser robusta antes que excesivamente compleja: menos bloques discretos cuando un integrado confiable simplifica el diseño.
\end{itemize}

\textbf{Resultados:}
La arquitectura final quedó más clara: PT100 con excitación precisa de \SI{1}{mA} y acondicionamiento diferencial; SM-50 con excitación estable de \SI{10}{V} y amplificación instrumental.

\textbf{Dificultades:}
Ajustar el informe para que no quedaran mezcladas decisiones preliminares con decisiones finales ya corregidas.% =========================
\section{Decimocuarta semana}

% -------------------------
\subsection{Depuración de arquitectura y fuente de corriente del PT100}
\textbf{Fecha:} 08/06/2026 \quad \textbf{Hora:} 16:00--20:30

\textbf{Objetivo:}
Revisar la arquitectura del canal de temperatura y reducir riesgos de implementación en la fuente de corriente del PT100.

\textbf{Desarrollo:}
\begin{itemize}
\item Se revisó nuevamente la necesidad de excitar el PT100 con una corriente estable para convertir la variación de resistencia en una tensión proporcional a la temperatura.
\item Se comparó una fuente de corriente discreta basada en operacional, transistor y resistencia de ajuste frente a una alternativa integrada o una referencia de precisión con resistencia de programación.
\item Se identificó que una solución con menos bloques discretos facilita la explicación del diseño, reduce puntos de falla y mejora la repetibilidad en PCB.
\item Se mantuvo la prioridad de medir el PT100 en forma diferencial para aprovechar el rechazo de modo común y reducir errores por cableado.
\item Se reforzó que el canal de temperatura debe separar claramente tres conceptos: excitación del sensor, resta de offset y amplificación hacia el rango permitido por la adquisición.
\end{itemize}

\textbf{Resultados:}
Se consolidó la idea de usar una fuente de corriente precisa para el PT100 y mantener la medición diferencial como base del canal de temperatura.

\textbf{Dificultades:}
Evitar que el esquemático creciera innecesariamente con bloques discretos difíciles de ajustar y defender durante la exposición.

% -------------------------
\subsection{Revisión de referencias técnicas para RTD, puente Wheatstone y acondicionamiento}
\textbf{Fecha:} 10/06/2026 \quad \textbf{Hora:} 19:00--22:30

\textbf{Objetivo:}
Respaldar las decisiones del diseño con documentación técnica sobre sensores resistivos, RTD y puentes Wheatstone.

\textbf{Desarrollo:}
\begin{itemize}
\item Se revisaron notas de aplicación y material técnico sobre acondicionamiento de sensores resistivos y medición de señales diferenciales de baja amplitud.
\item Para el SM-50 se reforzó que el sensor se comporta como un puente Wheatstone de galgas extensométricas con salida de pocos milivoltios por voltio de excitación.
\item Se relacionó la necesidad del amplificador de instrumentación con la alta impedancia de entrada, el alto rechazo de modo común y la baja amplitud de la señal diferencial.
\item Para el PT100 se revisó el modelo resistivo del RTD y la conveniencia de una fuente de corriente para obtener una relación directa entre resistencia y tensión.
\item Se identificaron como temas clave para justificar el diseño: sensibilidad, offset, ganancia, filtrado, rango dinámico, protección y ruido.
\end{itemize}

\textbf{Resultados:}
Se obtuvo una base teórica más sólida para explicar por qué ambos canales requieren acondicionamiento analógico antes de la entrada diferencial de la BoomBox.

\textbf{Dificultades:}
Integrar referencias de fabricantes y teoría de sensores sin que el informe se volviera una copia de notas de aplicación.

% -------------------------
\subsection{Ajuste de alcance del proyecto y bloques mínimos de la PCB}
\textbf{Fecha:} 14/06/2026 \quad \textbf{Hora:} 15:00--19:30

\textbf{Objetivo:}
Ajustar el alcance práctico de la PCB para que el diseño fuera fabricable, explicable y compatible con el tiempo disponible.

\textbf{Desarrollo:}
\begin{itemize}
\item Se revisó la diferencia entre un diseño ampliado con varios canales y una versión mínima funcional para validar el principio de medición.
\item Se priorizó trabajar con un canal de PT100 y un canal de SM-50, manteniendo la posibilidad de replicar bloques si se requiere escalar el diseño.
\item Se separaron los bloques indispensables: entrada de sensor, protección, excitación, amplificación instrumental, filtrado de salida, alimentación y conectores hacia la BoomBox.
\item Se revisó que la PCB no debe digitalizar la señal, sino acondicionarla para que la adquisición se realice externamente.
\item Se identificó que reducir el alcance ayuda a mejorar el ruteo, el orden físico y la revisión de errores en KiCad.
\end{itemize}

\textbf{Resultados:}
El proyecto quedó enfocado en una PCB analógica de acondicionamiento para un PT100 y un SM-50, con bloques replicables y mejor control de complejidad.

\textbf{Dificultades:}
Recortar el alcance sin perder coherencia técnica ni dejar fuera protecciones necesarias para un entorno con motor e inversor.

% =========================
\section{Decimoquinta semana}

% -------------------------
\subsection{Simulación en LTspice y revisión de memoria de cálculo}
\textbf{Fecha:} 17/06/2026 \quad \textbf{Hora:} 14:00--20:00

\textbf{Objetivo:}
Verificar mediante simulación y cálculo los rangos esperados de los canales PT100 y SM-50.

\textbf{Desarrollo:}
\begin{itemize}
\item Se trabajó con esquemáticos de simulación para el canal PT100 y el canal SM-50 con el fin de comprobar niveles de señal antes de trasladarlos a KiCad.
\item En el canal PT100 se revisó la relación entre corriente de excitación, resistencia del sensor, tensión diferencial y ganancia necesaria.
\item Se comparó mantener \SI{1}{mA} frente a reducir la excitación del PT100 a aproximadamente \SI{0.5}{mA}, buscando menor autocalentamiento y mejor margen de consumo.
\item En el canal SM-50 se revisó la excitación del puente, la salida diferencial esperada y la ganancia del amplificador de instrumentación.
\item Se ajustaron valores de resistencias de ganancia para mantener la salida dentro del rango seguro de la adquisición.
\item Se revisó la memoria de cálculo para corregir decisiones preliminares y dejar coherencia entre cálculo, simulación y esquemático.
\end{itemize}

\textbf{Resultados:}
Se validó que los dos canales pueden entregar señales acondicionadas dentro del margen requerido, siempre que se controle la ganancia y el filtrado de salida.

\textbf{Dificultades:}
Mantener consistentes los valores entre LTspice, memoria de cálculo, lista de materiales y esquemático de KiCad.

% -------------------------
\subsection{Selección de amplificadores y reducción de costo del diseño}
\textbf{Fecha:} 18/06/2026 \quad \textbf{Hora:} 18:30--22:30

\textbf{Objetivo:}
Comparar opciones de amplificadores para lograr una solución precisa sin elevar innecesariamente el costo de la PCB.

\textbf{Desarrollo:}
\begin{itemize}
\item Se comparó el uso de INA828 frente a INA826 para los canales de acondicionamiento.
\item Se identificó que el INA826 representa una alternativa más económica para mantener una topología de instrumentación adecuada.
\item Se revisó el uso del OPA2188 como operacional de precisión para etapas auxiliares, principalmente donde el offset y la deriva pueden afectar la medición.
\item Se discutió que el PT100 no exige una arquitectura excesivamente compleja si la señal se acondiciona de forma limpia y se calibra correctamente.
\item Se revisó la necesidad de no sacrificar rechazo de modo común ni estabilidad por ahorrar componentes críticos.
\end{itemize}

\textbf{Resultados:}
Se orientó el diseño hacia el uso de amplificadores de instrumentación INA826 y operacionales de precisión para las funciones auxiliares necesarias.

\textbf{Dificultades:}
Balancear costo, disponibilidad, precisión y facilidad de justificación técnica.

% -------------------------
\subsection{Investigación de alimentación, LDO y límite de corriente de la B-Box}
\textbf{Fecha:} 19/06/2026 \quad \textbf{Hora:} 13:00--21:00

\textbf{Objetivo:}
Definir una alimentación realista para la PCB considerando que la B-Box entrega rieles limitados en corriente.

\textbf{Desarrollo:}
\begin{itemize}
\item Se revisó que la alimentación disponible desde la B-Box es de \(\pm\SI{15}{V}\) con una corriente limitada, por lo que el consumo total de la PCB debe mantenerse bajo control.
\item Se investigaron reguladores lineales tipo LDO en encapsulado SMD para generar una tensión limpia a partir del riel de entrada.
\item Se compararon opciones como reguladores de la familia 78L05/78M05 y reguladores de mayor calidad, considerando disponibilidad, ruido, corriente y facilidad de montaje.
\item Se definió que la excitación del SM-50 debe ser estable y de bajo ruido, debido a que cualquier variación de excitación afecta directamente la salida del puente.
\item Se revisó la opción de obtener \SI{10}{V} para el SM-50 desde el riel de \SI{15}{V} mediante regulación local, manteniendo la excitación separada de la señal de salida.
\item Se reforzó la necesidad de colocar capacitores de desacoplo cerca de los reguladores, referencias y amplificadores.
\end{itemize}

\textbf{Resultados:}
Se estableció que la alimentación debe partir de los rieles de la B-Box, con regulación local y desacoplo suficiente para referencias, excitación del SM-50 y fuente de corriente del PT100.

\textbf{Dificultades:}
Elegir un regulador disponible y defendible sin exceder la corriente disponible ni introducir ruido en las señales de milivoltios.

% -------------------------
\subsection{Revisión de EMI, filtros y necesidad de protección en la PCB}
\textbf{Fecha:} 20/06/2026 \quad \textbf{Hora:} 16:00--20:00

\textbf{Objetivo:}
Definir medidas básicas contra ruido e interferencias para una PCB cercana a un sistema de potencia.

\textbf{Desarrollo:}
\begin{itemize}
\item Se revisó que el entorno del motor y del inversor puede introducir interferencia electromagnética por acoplamiento capacitivo, inductivo y conducido.
\item Se discutió el uso de filtros RC en entradas y salidas para limitar ruido de alta frecuencia sin afectar la banda útil de torque y temperatura.
\item Se reforzó el uso de señales diferenciales y cableado blindado para reducir sensibilidad al ruido externo.
\item Se revisó que el blindaje de cables y conectores debe tratarse con cuidado para no contaminar el GND analógico sensible.
\item Se consideró la necesidad de TVS, fusibles rearmables y desacoplos como parte del diseño robusto, no como componentes opcionales decorativos.
\end{itemize}

\textbf{Resultados:}
Se definió que la PCB debe incorporar filtrado, protección y una organización física que separe sensores, acondicionamiento, alimentación y salidas.

\textbf{Dificultades:}
Evitar llenar el esquemático de filtros innecesarios, pero sin dejar expuestas entradas y alimentaciones sensibles.

% -------------------------
\subsection{Integración del esquemático en KiCad y corrección de errores ERC}
\textbf{Fecha:} 21/06/2026 \quad \textbf{Hora:} 10:00--22:00

\textbf{Objetivo:}
Avanzar la integración del esquemático final en KiCad y resolver errores eléctricos antes de pasar al layout.

\textbf{Desarrollo:}
\begin{itemize}
\item Se revisaron símbolos, footprints y etiquetas de red para que las etapas quedaran conectadas correctamente.
\item Se corrigieron problemas relacionados con pines de alimentación, referencias y uso de \texttt{PWR\_FLAG} en KiCad.
\item Se definieron etiquetas claras para unir bloques de salida, resistencias limitadoras, trimmers, resistencias de aislamiento y salidas diferenciales.
\item Se revisó la asignación de footprints para componentes SMD principales, incluyendo amplificadores, referencia, reguladores, capacitores y resistencias.
\item Se depuraron componentes no utilizados para reducir ruido visual en el esquemático y evitar confusiones en la lista de materiales.
\end{itemize}

\textbf{Resultados:}
El esquemático quedó más ordenado y preparado para pasar al diseño físico, con conexiones más claras entre bloques funcionales.

\textbf{Dificultades:}
Resolver errores de KiCad sin esconder problemas reales de alimentación o conexión entre bloques.

% =========================
\section{Decimosexta semana}

% -------------------------
\subsection{Selección e importación de protecciones TVS y fusibles rearmables}
\textbf{Fecha:} 22/06/2026 \quad \textbf{Hora:} 09:00--18:00

\textbf{Objetivo:}
Agregar protecciones eléctricas al diseño y asegurar que los símbolos y huellas fueran compatibles con fabricación.

\textbf{Desarrollo:}
\begin{itemize}
\item Se revisó el uso de TVS para proteger líneas expuestas frente a eventos transitorios y descargas electrostáticas.
\item Se incorporó la protección TVS de \SI{12}{V} para la zona de entrada de sensores y se revisó su conexión respecto a la señal y tierra de referencia.
\item Se revisaron TVS/ESD de \SI{5.5}{V} para líneas sensibles hacia la interfaz de adquisición, especialmente donde se requiere proteger entradas de bajo nivel.
\item Se incluyeron fusibles rearmables PPTC en las entradas de alimentación para limitar fallas por sobrecorriente o errores de conexión.
\item Se importaron y verificaron símbolos y footprints, corrigiendo pines y encapsulados cuando no coincidían con el componente real.
\end{itemize}

\textbf{Resultados:}
El diseño incorporó protecciones más robustas mediante TVS y PPTC, manteniendo una organización por bloques para facilitar revisión y ruteo.

\textbf{Dificultades:}
Diferenciar qué protección corresponde a alimentación, a entradas de sensores y a líneas de salida hacia la BoomBox.

% -------------------------
\subsection{Conectores, RJ45 blindados y organización de ciudades de la PCB}
\textbf{Fecha:} 22/06/2026 \quad \textbf{Hora:} 19:00--23:30

\textbf{Objetivo:}
Definir el acomodo físico de conectores y bloques funcionales antes de comenzar el ruteo principal.

\textbf{Desarrollo:}
\begin{itemize}
\item Se mantuvo el uso de conectores RJ45 blindados para la conexión con la BoomBox y cable FTP CAT5.
\item Se revisó la asignación de pines de la interfaz RJ45 considerando rieles de \(\pm\SI{15}{V}\), GND y entrada diferencial.
\item Se separó el tratamiento del blindaje respecto al GND analógico para evitar que corrientes de pantalla circulen por rutas sensibles.
\item Se ordenó el layout por ciudades: entradas de sensores, canal SM-50, canal PT100, alimentación/protecciones, salidas RJ45 y zona de documentación.
\item Se definió que los conectores de sensores deben ubicarse cerca de sus protecciones, mientras que los conectores hacia BoomBox deben quedar del lado de salida.
\end{itemize}

\textbf{Resultados:}
La PCB quedó organizada con una lógica física más clara, reduciendo cruces de señales y separando zonas ruidosas de zonas sensibles.

\textbf{Dificultades:}
Ubicar conectores grandes, borneras, fusibles, TVS y circuitos integrados sin romper la separación entre señales de entrada, alimentación y salida.

% -------------------------
\subsection{Ruteo preliminar y definición de anchos de pista}
\textbf{Fecha:} 24/06/2026 \quad \textbf{Hora:} 09:00--21:00

\textbf{Objetivo:}
Iniciar el ruteo de la PCB usando reglas prácticas para señales sensibles, alimentación y conexiones de salida.

\textbf{Desarrollo:}
\begin{itemize}
\item Se revisó el ruteo por ciudades para mantener señales de milivoltios lejos de reguladores, conectores de alimentación y retornos con corriente.
\item Se asignaron anchos de pista distintos para señales analógicas, alimentación, excitación de sensores y salidas hacia conectores.
\item Se evaluó cuándo usar una segunda capa para evitar cruces y mantener rutas cortas, especialmente en zonas congestionadas cerca de conectores.
\item Se revisó la necesidad de colocar capacitores de desacoplo cerca de cada circuito integrado y de mantener los filtros cerca de los pines que protegen.
\item Se corrigieron problemas de elementos bloqueados en KiCad y se mantuvieron fijos el marco y los agujeros de montaje.
\end{itemize}

\textbf{Resultados:}
Se obtuvo un ruteo preliminar más ordenado, con criterios diferenciados para pistas de señal, alimentación y protección.

\textbf{Dificultades:}
El mayor problema fue la congestión cerca de conectores y componentes de protección, donde no siempre era posible usar el ancho de pista ideal.

% -------------------------
\subsection{Revisión de footprints mecánicos y dimensiones de borneras}
\textbf{Fecha:} 25/06/2026 \quad \textbf{Hora:} 10:00--13:00

\textbf{Objetivo:}
Verificar que los componentes mecánicos principales tuvieran espacio suficiente en la PCB.

\textbf{Desarrollo:}
\begin{itemize}
\item Se revisaron las dimensiones físicas de las borneras utilizadas para entrada de sensores.
\item Se buscó definir el rectángulo de ocupación de cada bornera para dejar espacio alrededor y evitar interferencia con otros componentes.
\item Se consideró que las borneras deben quedar accesibles para cableado, ferrules y manipulación durante pruebas de laboratorio.
\item Se verificó que los conectores grandes condicionan el borde de la PCB y el orden de las ciudades cercanas.
\item Se mantuvo el criterio de dejar los componentes de protección cerca de los conectores de entrada.
\end{itemize}

\textbf{Resultados:}
Se mejoró la planificación mecánica del layout, especialmente en la ubicación de borneras, conectores y protecciones de entrada.

\textbf{Dificultades:}
Ajustar componentes grandes en una placa compacta sin perder claridad de ruteo ni accesibilidad para pruebas.

% -------------------------
\subsection{Preparación del póster electrónico y síntesis de avances}
\textbf{Fecha:} 25/06/2026 \quad \textbf{Hora:} 15:00--18:30

\textbf{Objetivo:}
Preparar la información del proyecto para la exposición tipo póster electrónico de IE0499.

\textbf{Desarrollo:}
\begin{itemize}
\item Se revisó la rúbrica de exposición para priorizar avances, dificultades y aprendizaje incorporado durante el desarrollo del proyecto.
\item Se definió que el póster debe ser horizontal, legible en pantalla y con máximo dos transparencias.
\item Se organizaron los contenidos principales: problema, objetivo, arquitectura de la PCB, avances técnicos, dificultades y conclusiones.
\item Se seleccionaron como avances principales la definición de los canales PT100 y SM-50, la integración en KiCad, la selección de protecciones y el inicio del ruteo.
\item Se seleccionaron como dificultades principales el control de ruido, la limitación de corriente de la B-Box, la importación de footprints y la congestión del layout.
\end{itemize}

\textbf{Resultados:}
Se obtuvo una estructura de póster más enfocada en explicar decisiones técnicas y dificultades reales, no solo en mostrar el circuito terminado.

\textbf{Dificultades:}
Sintetizar varias semanas de trabajo en pocas ideas claras que puedan defenderse durante preguntas de otras áreas.

% =========================
\section{Decimoséptima semana}

% -------------------------
\subsection{Actualización final de valores del canal SM-50 y PT100}
\textbf{Fecha:} 26/06/2026 \quad \textbf{Hora:} 18:00--23:30

\textbf{Objetivo:}
Actualizar los cálculos del proyecto con los valores finales realmente usados en la PCB y separar las decisiones vigentes de las memorias antiguas.

\textbf{Desarrollo:}
\begin{itemize}
\item Se revisaron los cálculos finales del canal de torque SM-50, manteniendo la excitación del puente en \(\SI{10}{V}\) y usando la sensibilidad nominal de \(\SI{3}{mV/V}\), por lo que la señal diferencial máxima esperada del puente es aproximadamente \(\pm\SI{30}{mV}\).
\item Se mantuvo la resistencia de ganancia del amplificador de instrumentación del canal SM-50 como dos resistencias en serie, \(\SI{160}{\ohm}+\SI{180}{\ohm}\), para obtener \(R_G=\SI{340}{\ohm}\).
\item Se conservó la resistencia en serie de \(\SI{180}{\ohm}\), ya que corresponde a la versión del acondicionamiento con salida bipolar nominal de \(\pm\SI{4.39}{V}\) para el SM-50.
\item Se corrigió el canal de temperatura indicando que la excitación final del PT100 se toma como \(I_{exc}=\SI{0.5}{mA}\), no \(\SI{1}{mA}\), con el propósito de reducir autocalentamiento y mantener bajo el consumo.
\item Se mantuvo el criterio del PT100 de tres hilos, usando medición diferencial, compensación de cableado, referencia de offset y ajuste de nivel antes de entregar la señal a la BoomBox.
\item Se dejó como valor vigente para el canal PT100 una resistencia de ganancia del INA de \(R_G=\SI{1}{k\ohm}\), separando este dato de valores preliminares usados en cálculos anteriores.
\item Se verificó que ambos canales requieren ajuste de nivel/salida: el canal SM-50 para escalar la salida hacia el rango útil bipolar de la BoomBox, y el canal PT100 para tratar el offset propio de la resistencia base de \(\SI{100}{\ohm}\).
\end{itemize}

\textbf{Resultados:}
Se actualizaron los valores finales del diseño: SM-50 con \(R_G=\SI{340}{\ohm}\), formado por \(\SI{160}{\ohm}+\SI{180}{\ohm}\), salida bipolar nominal de \(\pm\SI{4.39}{V}\); y PT100 con \(I_{exc}=\SI{0.5}{mA}\) y \(R_G=\SI{1}{k\ohm}\).

\textbf{Dificultades:}
La principal dificultad fue no mezclar valores de memorias antiguas con los datos finales del circuito, especialmente en la corriente de excitación del PT100 y en la ganancia del SM-50.

% -------------------------
\subsection{Validación de interfaz BoomBox, 8P8C y cable FTP Cat5}
\textbf{Fecha:} 26/06/2026 \quad \textbf{Hora:} 23:30--02:00

\textbf{Objetivo:}
Confirmar la conexión física y eléctrica entre la PCB y la BoomBox usando conectores 8P8C/RJ45 y cable FTP Cat5.

\textbf{Desarrollo:}
\begin{itemize}
\item Se revisó el manual de la BoomBox para confirmar que la entrada analógica puede configurarse en modo de alta impedancia diferencial de \(\SI{3}{k\ohm}\).
\item Se verificó que la BoomBox entrega alimentación para sensores externos mediante el conector analógico, con rieles de \(\pm\SI{15}{V}\) y corriente máxima de \(\SI{100}{mA}\).
\item Se actualizó la documentación para indicar que la conexión física entre la PCB y la BoomBox se realiza mediante cable FTP Cat5 y conector modular 8P8C blindado.
\item Se mantuvo la asignación de pines del conector: pines 1 y 2 para \(+\SI{15}{V}\), pines 3 y 6 para \(\SI{0}{V}\), pines 4 y 5 para señal analógica diferencial, y pines 7 y 8 para \(-\SI{15}{V}\).
\item Se aclaró que el conector 8P8C no se utiliza como Ethernet, sino como interfaz física multipar para alimentación y señal analógica.
\item Se definió que el par de señal debe mantenerse como par trenzado y que el blindaje del conector debe tratarse como pantalla, evitando mezclarlo directamente con el retorno analógico sensible.
\end{itemize}

\textbf{Resultados:}
Se corrigió la representación de la interfaz hacia BoomBox: entrada de alta impedancia diferencial, alimentación limitada a \(\pm\SI{15}{V}\) y \(\SI{100}{mA}\), transporte por FTP Cat5/8P8C y separación clara entre señal, alimentación y blindaje.

\textbf{Dificultades:}
Interpretar correctamente el conector RJ45, ya que físicamente se parece a una red Ethernet, pero en el proyecto funciona como interfaz analógica y de alimentación.

% -------------------------
\subsection{Separación de memorias antiguas y trazabilidad del proceso}
\textbf{Fecha:} 27/06/2026 \quad \textbf{Hora:} 00:00--03:00

\textbf{Objetivo:}
Organizar los documentos previos del proyecto para conservarlos como evidencia del proceso sin usar sus valores obsoletos como cálculos finales.

\textbf{Desarrollo:}
\begin{itemize}
\item Se revisaron memorias antiguas, avances preliminares y documentos de arquitectura generados durante el desarrollo del proyecto.
\item Se clasificó como información vigente únicamente lo relacionado con el pinout 8P8C/RJ45, el uso de cable FTP/STP, la separación de puertos por canal y la justificación conceptual de los sensores resistivos.
\item Se marcó como obsoleta la información asociada a ADC de \SI{12}{bits}, referencia de \SI{3.3}{V}, PT100 con \SI{1}{mA} como valor final, ganancias preliminares y BOM anteriores.
\item Se conservó la información teórica útil: modelo del PT100, conexión de tres hilos, fuente de corriente para RTD, puente Wheatstone completo, sensibilidad del SM-50 y necesidad de amplificación instrumental.
\item Se redactó una nota de trazabilidad indicando que los documentos anteriores explican la evolución del diseño, pero que la memoria final usa los valores actuales.
\end{itemize}

\textbf{Resultados:}
Se evitó que la memoria final mezclara cálculos viejos con el diseño actual. Las memorias antiguas quedaron como respaldo histórico del proceso de aprendizaje y toma de decisiones.

\textbf{Dificultades:}
Distinguir qué partes de documentos anteriores seguían siendo útiles como referencia conceptual y cuáles debían descartarse para no generar contradicciones técnicas.

% -------------------------
\subsection{Actualización de memoria de cálculo, referencias y diagrama final}
\textbf{Fecha:} 27/06/2026 \quad \textbf{Hora:} 03:00--06:00

\textbf{Objetivo:}
Actualizar la memoria de cálculo del proyecto con los valores actuales, referencias completas y diagramas finales.

\textbf{Desarrollo:}
\begin{itemize}
\item Se actualizó la memoria de cálculo del proyecto separando los cálculos finales de la trazabilidad de documentos previos.
\item Se incorporaron los valores actuales del canal PT100: \(I_{exc}=\SI{0.5}{mA}\), \(R_G=\SI{1}{k\ohm}\), conexión de tres hilos, referencia de offset proveniente de la B-Box o derivada de ella, filtro y ajuste de nivel/salida.
\item Se incorporaron los valores actuales del canal SM-50: excitación de puente de \(\SI{10}{V}\), sensibilidad nominal de \(\SI{3}{mV/V}\), salida diferencial cruda de \(\pm\SI{30}{mV}\), \(R_G=\SI{340}{\ohm}\) mediante \(\SI{160}{\ohm}+\SI{180}{\ohm}\), y salida bipolar nominal de \(\pm\SI{4.39}{V}\).
\item Se actualizó el diagrama de bloques final para mostrar los dos canales con protección, amplificación instrumental, filtro pasabajo, ajuste de nivel/salida y conexión hacia BoomBox mediante FTP Cat5/8P8C.
\item Se incorporaron referencias completas guardadas en la carpeta del proyecto, incluyendo el manual de BoomBox, hoja de datos del SM-50, notas de aplicación de puentes Wheatstone, documentación de ruido, guías de KiCad y el texto de Pallás-Areny como referencia teórica principal.
\item Se generó una versión actualizada de la memoria en PDF y DOCX, junto con archivos auxiliares de cálculos y referencias.
\end{itemize}

\textbf{Resultados:}
La documentación quedó actualizada al estado actual del proyecto, con valores vigentes, referencias completas, diagrama final y separación explícita entre memoria final y memorias antiguas.

\textbf{Dificultades:}
La dificultad principal fue mantener consistencia entre memoria, diagrama, cálculos, referencias y bitácora, debido a que el proyecto tuvo varios cambios de valores durante su desarrollo.

% -------------------------
\subsection{Estado del proyecto al cierre de la actualización}
\textbf{Fecha:} 27/06/2026 \quad \textbf{Hora:} 06:00--07:00

\textbf{Objetivo:}
Registrar el estado final del proyecto al día de la actualización de la bitácora.

\textbf{Desarrollo:}
\begin{itemize}
\item El diseño queda definido como una PCB analógica de acondicionamiento para un sensor de torque SM-50 y sensores PT100, con bloques replicables para ampliar canales si se requiere.
\item La PCB recibe alimentación desde la BoomBox/B-Box por medio del conector 8P8C, usando \(\pm\SI{15}{V}\) con límite de \(\SI{100}{mA}\).
\item La adquisición final se realiza en la BoomBox; la PCB no digitaliza la señal, sino que la protege, excita, amplifica, filtra y ajusta antes de enviarla como señal analógica.
\item La interfaz física final queda definida mediante cable FTP Cat5, conectores 8P8C blindados y modo de entrada de alta impedancia diferencial.
\item El canal SM-50 queda como el canal con mayor exigencia de ganancia por partir de una señal diferencial de milivolts.
\item El canal PT100 queda definido con menor corriente de excitación para reducir autocalentamiento, manteniendo compensación por tres hilos y ajuste de offset.
\item La bitácora queda actualizada hasta el 27/06/2026 con las decisiones finales, manteniendo los documentos viejos solo como parte del proceso.
\end{itemize}

\textbf{Resultados:}
Se cuenta con una bitácora actualizada, coherente con la memoria final y con los valores actuales del diseño.

\textbf{Dificultades:}
Documentar el cierre de forma clara sin borrar el proceso previo, ya que las decisiones antiguas también fueron importantes para llegar a la versión final.

\begin{thebibliography}{99}

\bibitem{InterfaceSM50}
Interface, Inc. \emph{SM S-Type Load Cell: Datasheet}. Información técnica del sensor tipo puente Wheatstone.

\bibitem{InterfaceWiring}
Interface, Inc. \emph{Electrical \& Wiring Diagram}. Información de cableado para sensores de carga y torque.

\bibitem{TIBridgeSensors}
Texas Instruments. \emph{Signal Conditioning Wheatstone Resistive Bridge Sensors}. Application Report SLOA034.

\bibitem{TIStrainGauge}
Texas Instruments. \emph{Single-Supply Strain Gauge Bridge Amplifier Circuit}. SBOA247A.

\bibitem{ADBridgeCircuits}
Analog Devices. \emph{AN-43: Bridge Circuits}. Nota de aplicación sobre puentes resistivos y acondicionamiento.

\bibitem{ADBridgeADC}
Analog Devices. \emph{AN-96: Delta Sigma ADC Bridge Measurement Techniques}. Nota de aplicación sobre medición de puentes y resolución.

\bibitem{RuidoPCB}
R. Cárdenas Dobson. \emph{Atenuación de ruidos en circuitos electrónicos}. Apuntes del curso de proyecto, Universidad de Magallanes.

\bibitem{KiCadGuide}
Guía de proyecto. \emph{Guía para importar símbolos, huellas y modelos 3D en KiCad}.

\bibitem{Imperix}
imperix. \emph{Documentación técnica de módulos analógicos y BoomBox}. Referencia para interfaz analógica diferencial y conectores tipo RJ45.

\bibitem{PallasAreny}
R. Pallás-Areny, O. Casas y R. Bragós. \emph{Sensores y acondicionadores de señal: Problemas resueltos}. Ediciones de la Universitat Politècnica de Catalunya / Alfaomega, Barcelona, España, 2007.

\bibitem{MeasurementComputing}
Measurement Computing Corporation. \emph{Signal Conditioning \& PC-Based Data Acquisition Handbook}. 3rd ed., Measurement Computing Corporation, 2012.

\bibitem{BoomBoxManual}
imperix ltd. \emph{BoomBox User Manual}. Manual técnico de entradas analógicas, alimentación de sensores, filtros, ADC y conectores ModuLink/RJ45.

\bibitem{INA826}
Texas Instruments. \emph{INA826 Precision Instrumentation Amplifier}. Datasheet.

\bibitem{INA828}
Texas Instruments. \emph{INA828 Precision Instrumentation Amplifier}. Datasheet.

\bibitem{OPA2188}
Texas Instruments. \emph{OPA2188 Zero-Drift Operational Amplifier}. Datasheet.

\bibitem{REF3012}
Texas Instruments. \emph{REF3012 Precision Voltage Reference}. Datasheet.

\bibitem{TPS7A49}
Texas Instruments. \emph{TPS7A4901 High-Voltage Low-Noise Linear Regulator}. Datasheet.

\bibitem{MemoriasProceso}
Documentos internos del proyecto. \emph{Memorias preliminares, avances, diagramas y cálculos históricos de la PCB}. Usados como trazabilidad del proceso y no como valores finales.

\end{thebibliography}

\end{document}

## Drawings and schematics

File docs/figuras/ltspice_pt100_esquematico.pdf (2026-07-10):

# IN- VCC VEE

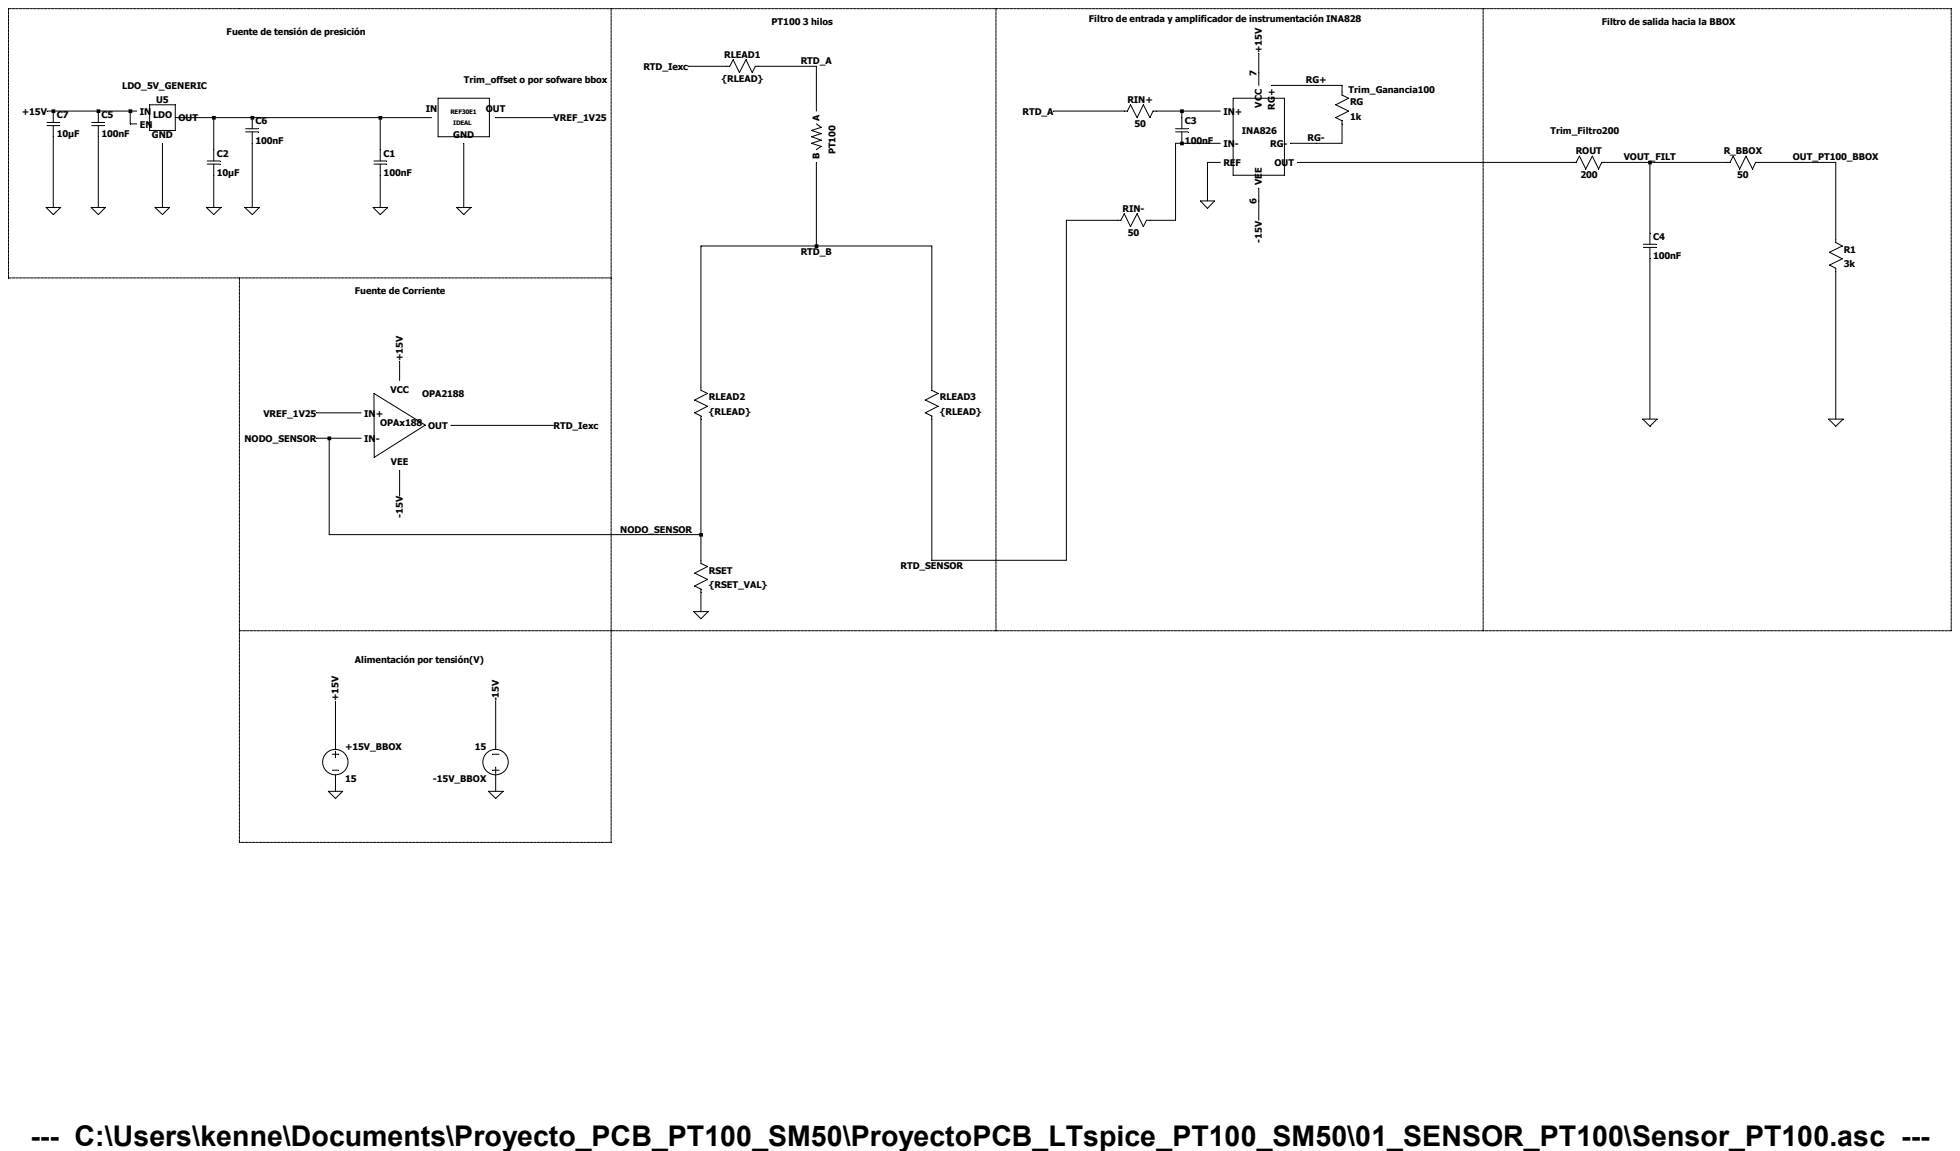
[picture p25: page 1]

Fuente de tensión de presición

--- C:\Users\kenne\Documents\Proyecto_PCB_PT100_SM50\ProyectoPCB_LTspice_PT100_SM50\01_SENSOR_PT100\Sensor_PT100.asc ---

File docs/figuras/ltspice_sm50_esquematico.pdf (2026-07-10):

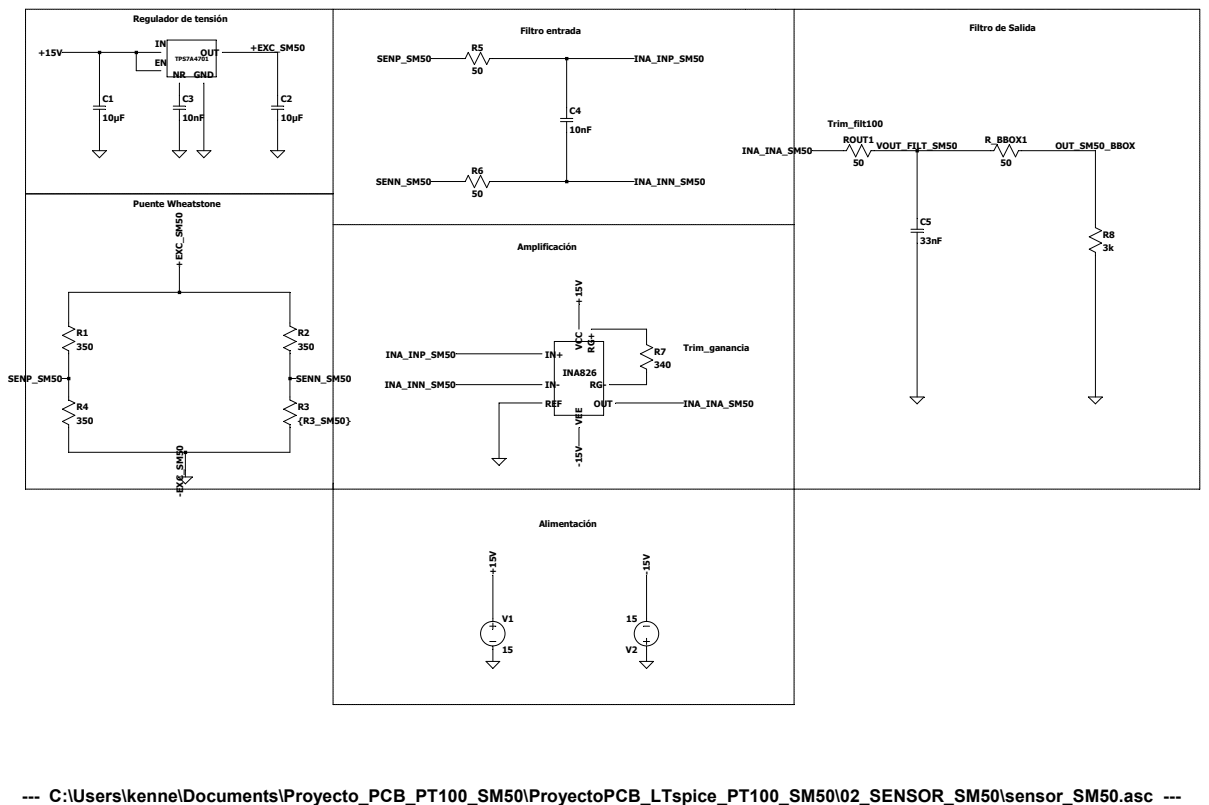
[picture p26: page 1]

--- C:\Users\kenne\Documents\Proyecto_PCB_PT100_SM50\ProyectoPCB_LTspice_PT100_SM50\02_SENSOR_SM50\sensor_SM50.asc ---

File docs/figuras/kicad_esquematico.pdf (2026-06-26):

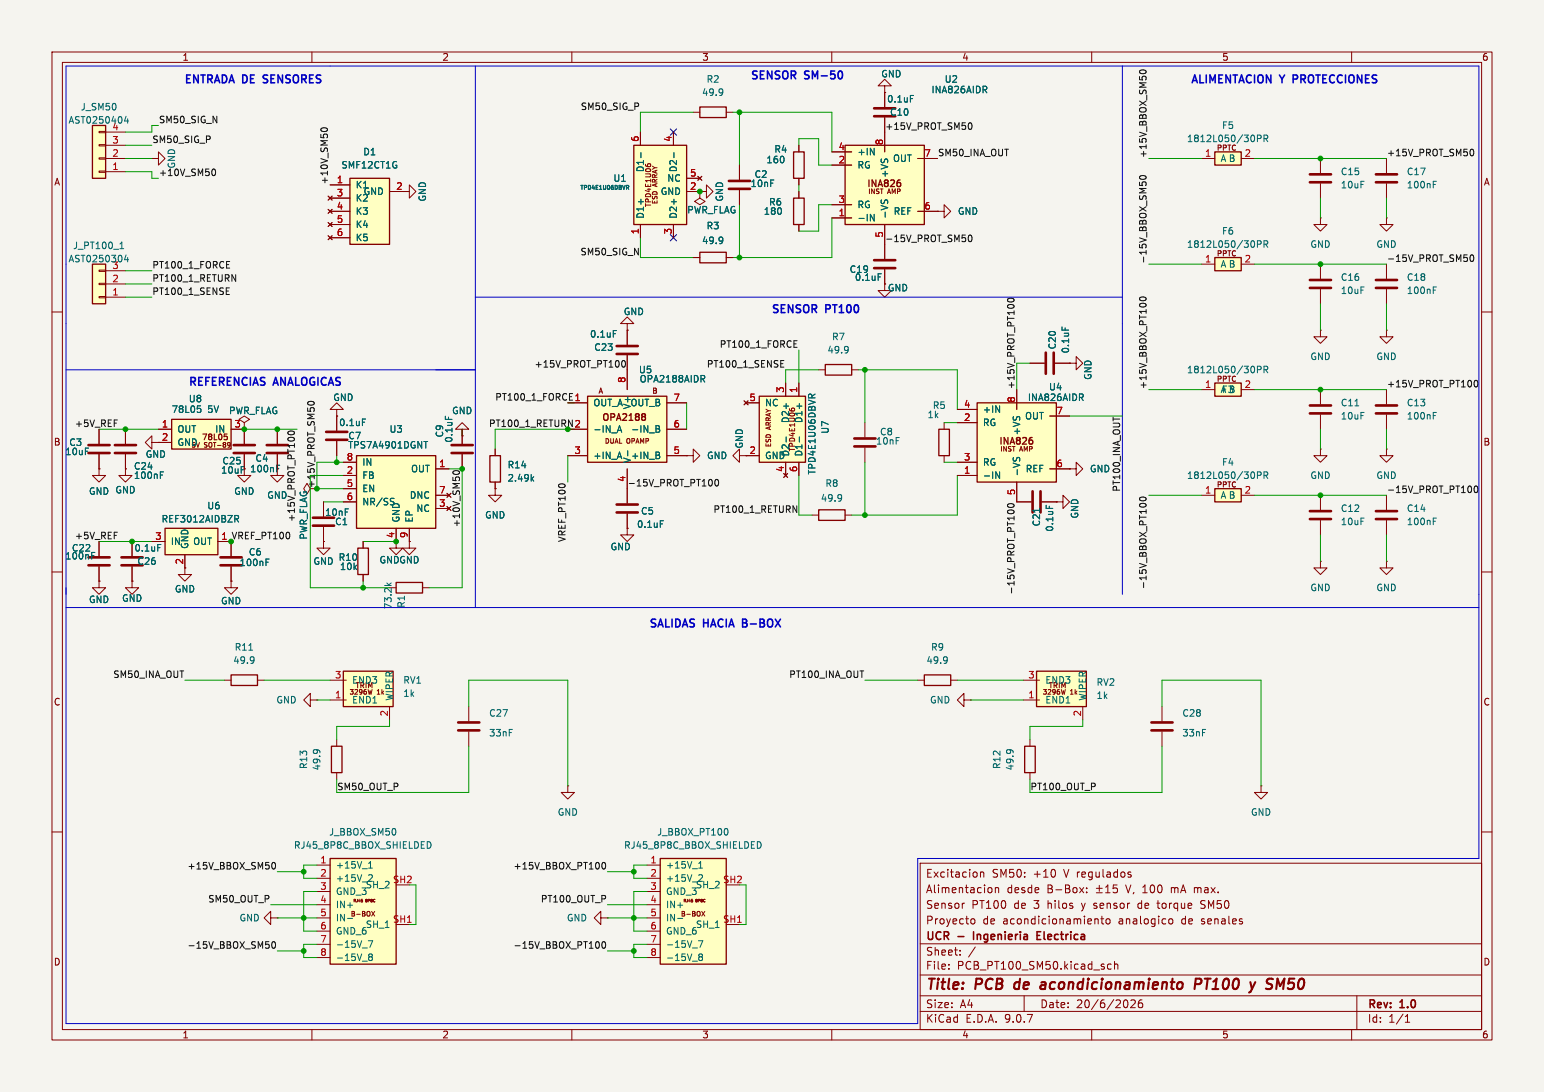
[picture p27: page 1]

5 OUT 7 REF 6 GND C20 0.1uF GND C21 0.1uFGND GND

3 NC 5 GND 2 D1- 6 D2- 4 GND GND

9 OUT 1 DNC 7 NC 3 U3 TPS7A4901DGNT GND GND

9 OUT 1 DNC 7 NC 3 GND

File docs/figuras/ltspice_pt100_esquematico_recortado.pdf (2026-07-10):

# IN- VCC VEE

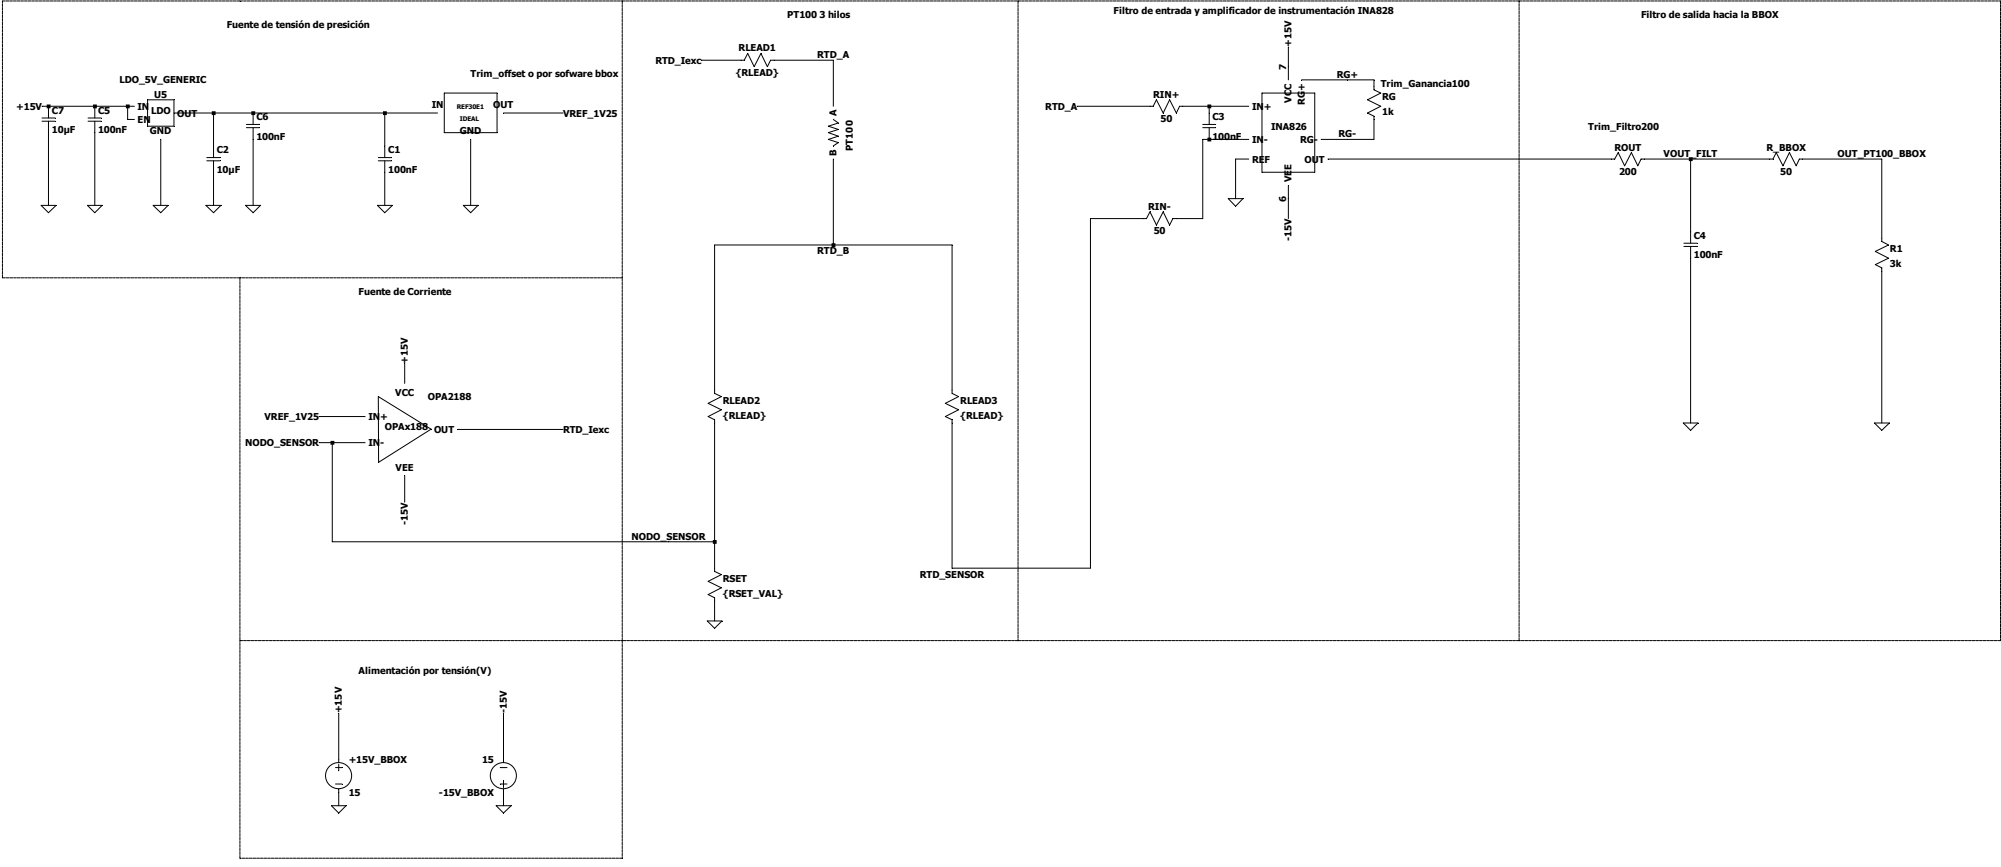
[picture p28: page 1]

Fuente de tensión de presición

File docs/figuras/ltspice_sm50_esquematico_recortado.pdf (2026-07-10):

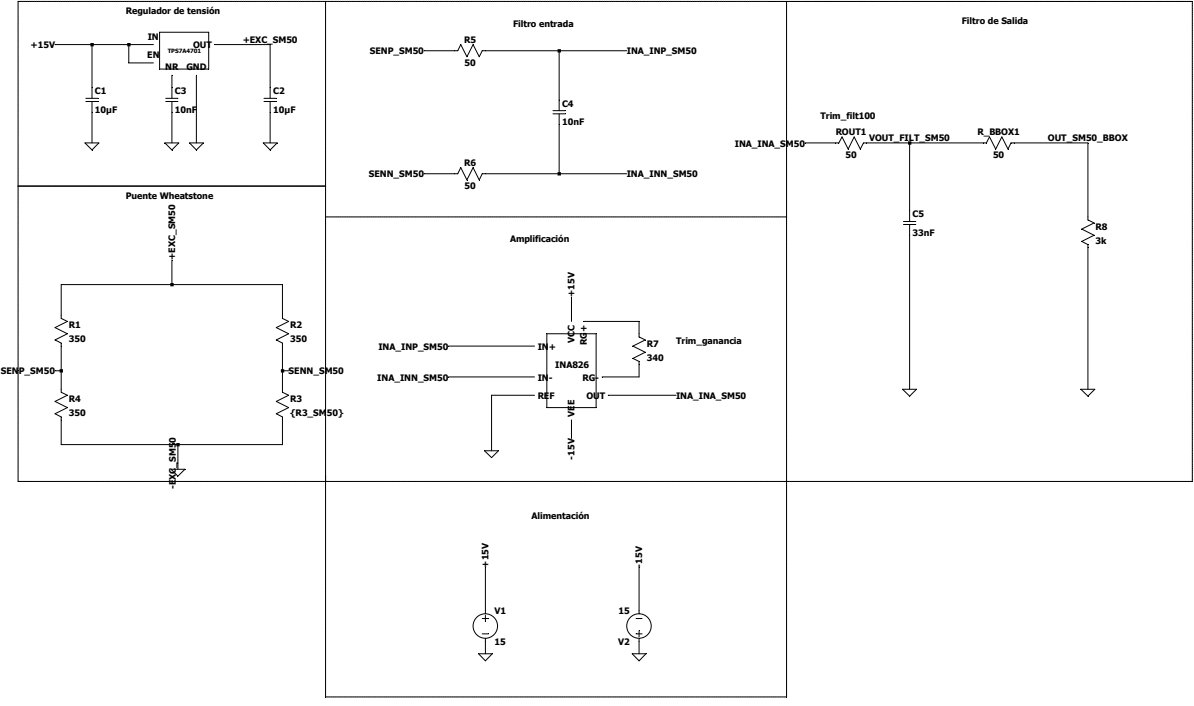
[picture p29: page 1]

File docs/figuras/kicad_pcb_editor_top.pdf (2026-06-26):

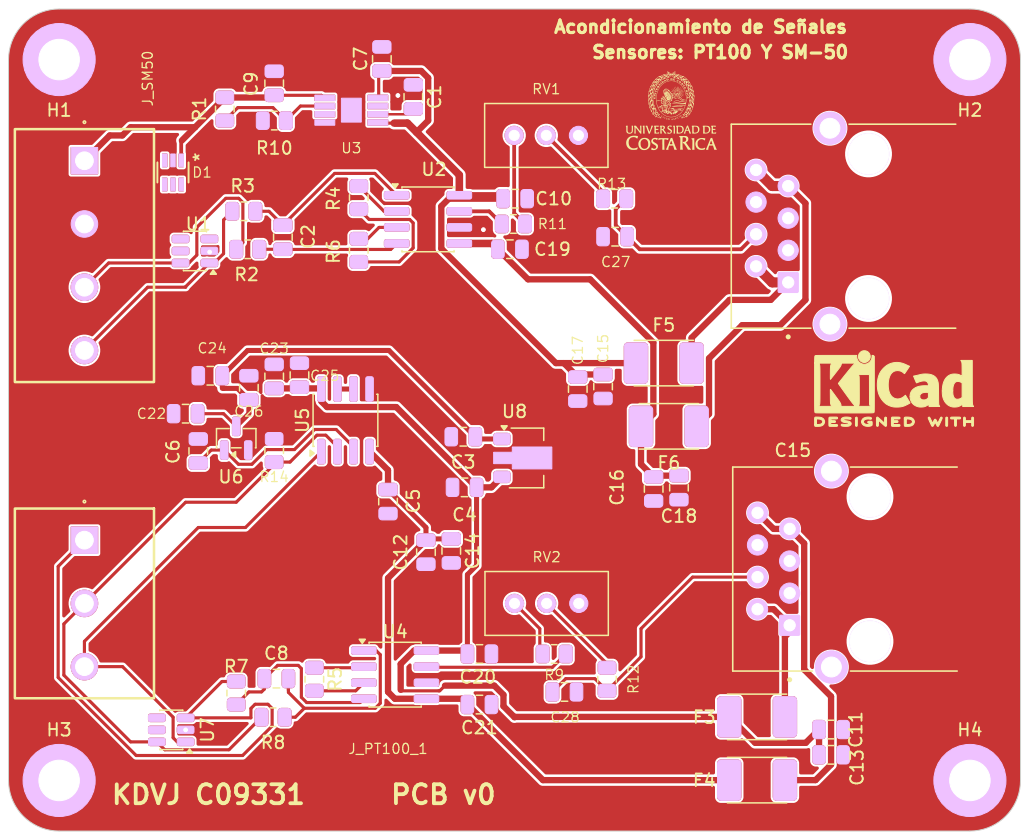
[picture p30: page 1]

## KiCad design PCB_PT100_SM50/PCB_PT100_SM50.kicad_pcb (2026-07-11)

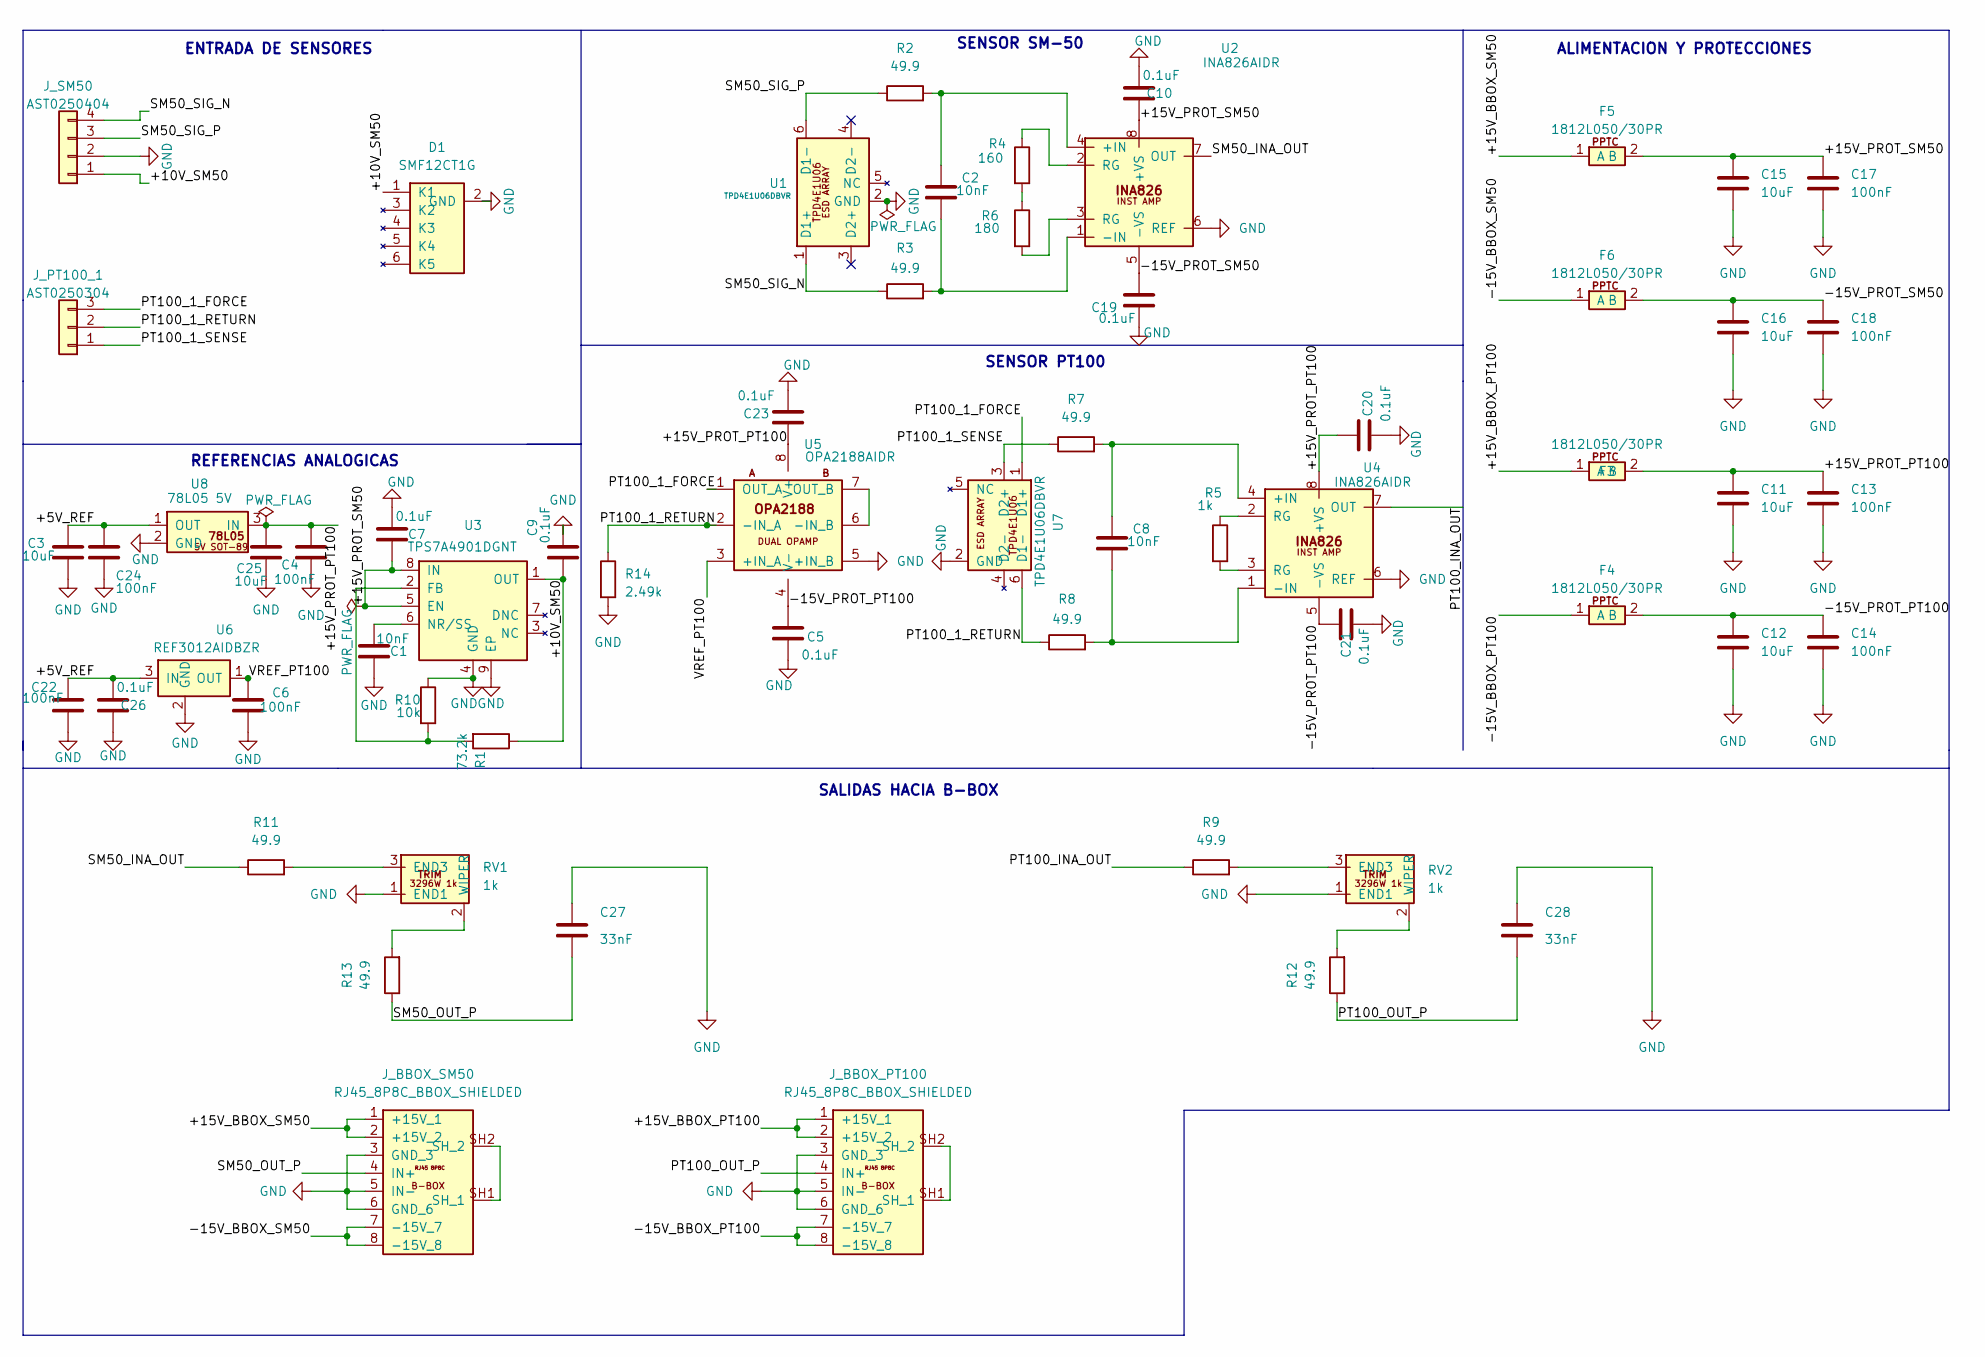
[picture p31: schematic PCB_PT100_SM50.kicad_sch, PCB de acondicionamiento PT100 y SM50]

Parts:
C1, C2, C8: 10nF; C_0805_2012Metric
C3, C11, C12, C15, C16, C25: 10uF; C_0805_2012Metric
C4, C6, C13, C14, C17, C18, C22, C24: 100nF; C_0805_2012Metric
C5, C7, C9, C10, C19, C20, C21, C23, C26: 0.1uF; C_0805_2012Metric
C27, C28: 33nF; C_0805_2012Metric
D1: SMF12CT1G; SMF12CT1G_SC88_SOT363
F3, F4, F5, F6: 1812L050/30PR; PPTC_1812L050_30PR_1812
J_BBOX_PT100: RJ45_8P8C_BBOX_SHIELDED; BEL_2250066-1
J_BBOX_SM50: RJ45_8P8C_BBOX_SHIELDED; BEL_2250066-1
J_PT100_1: AST0250304; CONN_AST0250304_MZC
J_SM50: AST0250404
R1: 73.2k; R_0805_2012Metric
R2, R3, R7, R8, R9, R11, R12, R13: 49.9; R_0805_2012Metric
R4: 160; R_0805_2012Metric
R5: 1k; R_0805_2012Metric
R6: 180; R_0805_2012Metric
R10: 10k; R_0805_2012Metric
R14: 2.49k; R_0805_2012Metric
RV1, RV2: 1k; Potentiometer_Bourns_3296W_Vertical
U1, U7: TPD4E1U06DBVR; SOT-23-6
U2, U4: INA826AIDR; SOIC-8_3.9x4.9mm_P1.27mm
U3: TPS7A4901DGNT; TPS7A4901DGNT_DGN8_1P89X1P57
U5: OPA2188AIDR; SOIC-8_3.9x4.9mm_P1.27mm
U6: REF3012AIDBZR; SOT-23
U8: 78L05 5V; SOT-89-3

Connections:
/+5V_REF: C3.1, C22.1, C24.1, C26.2, U6.3 (IN), U8.1 (OUT)
/+10V_SM50: C9.1, D1.1 (K1), J_SM50.1, R1.1, U3.1 (OUT)
/+15V_BBOX_PT100: F3.1 (A), J_BBOX_PT100.1 (+15V_1), J_BBOX_PT100.2 (+15V_2)
/+15V_BBOX_SM50: F5.1 (A), J_BBOX_SM50.1 (+15V_1), J_BBOX_SM50.2 (+15V_2)
/+15V_PROT_PT100: C4.1, C11.1, C13.1, C20.1, C23.1, C25.1, F3.2 (B), U4.8 (+VS), U5.8 (V+), U8.3 (IN)
/+15V_PROT_SM50: C7.1, C10.1, C15.1, C17.1, F5.2 (B), U2.8 (+VS), U3.5 (EN), U3.8 (IN)
/-15V_BBOX_PT100: F4.1 (A), J_BBOX_PT100.7 (-15V_7), J_BBOX_PT100.8 (-15V_8)
/-15V_BBOX_SM50: F6.1 (A), J_BBOX_SM50.7 (-15V_7), J_BBOX_SM50.8 (-15V_8)
/-15V_PROT_PT100: C5.1, C12.1, C14.1, C21.1, F4.2 (B), U4.5 (-VS), U5.4 (V-)
/-15V_PROT_SM50: C16.1, C18.1, C19.1, F6.2 (B), U2.5 (-VS)
/PT100_1_FORCE: J_PT100_1.3, U5.1 (OUT_A), U7.1 (D1+)
/PT100_1_RETURN: J_PT100_1.2, R8.1, R14.1, U5.2 (-IN_A), U7.6 (D1-)
/PT100_1_SENSE: J_PT100_1.1, R7.1, U7.3 (D2+)
/PT100_INA_OUT: R9.1, U4.7 (OUT)
/PT100_OUT_P: C28.2, J_BBOX_PT100.4 (IN+), R12.1
/SM50_INA_OUT: R11.1, U2.7 (OUT)
/SM50_OUT_P: C27.2, J_BBOX_SM50.4 (IN+), R13.1
/SM50_SIG_N: J_SM50.4, R3.1, U1.1 (D1+)
/SM50_SIG_P: J_SM50.3, R2.1, U1.6 (D1-)
/VREF_PT100: C6.1, U5.3 (+IN_A), U6.1 (OUT)
GND: C1.1, C3.2, C4.2, C5.2, C6.2, C7.2, C9.2, C10.2, C11.2, C12.2, C13.2, C14.2, C15.2, C16.2, C17.2, C18.2, C19.2, C20.2, C21.2, C22.2, C23.2, C24.2, C25.2, C26.1, C27.1, C28.1, D1.2 (GND), J_BBOX_PT100.3 (GND_3), J_BBOX_PT100.5 (IN-), J_BBOX_PT100.6 (GND_6), J_BBOX_SM50.3 (GND_3), J_BBOX_SM50.5 (IN-), J_BBOX_SM50.6 (GND_6), J_SM50.2, R10.1, R14.2, RV1.1 (END1), RV2.1 (END1), U1.2 (GND), U2.6 (REF), U3.4 (GND), U3.9 (EP), U4.6 (REF), U5.5 (+IN_B), U6.2 (GND), U7.2 (GND), U8.2 (GND); also elsewhere on the board
unnamed: J_BBOX_PT100.SH1 (SH_1), J_BBOX_PT100.SH2 (SH_2)
unnamed: J_BBOX_SM50.SH1 (SH_1), J_BBOX_SM50.SH2 (SH_2)
unnamed: R4.1, U2.2 (RG)
unnamed: R4.2, R6.1
unnamed: R5.1, U4.2 (RG)
unnamed: R5.2, U4.3 (RG)
unnamed: R6.2, U2.3 (RG)
unnamed: R11.2, RV1.3 (END3)
unnamed: R13.2, RV1.2 (WIPER)
unnamed: R9.2, RV2.3 (END3)
unnamed: R12.2, RV2.2 (WIPER)
unnamed: C2.1, R2.2, U2.4 (+IN)
unnamed: C2.2, R3.2, U2.1 (-IN)
unnamed: R1.2, R10.2, U3.2 (FB)
unnamed: C1.2, U3.6 (NR/SS)
unnamed: C8.1, R7.2, U4.4 (+IN)
unnamed: C8.2, R8.2, U4.1 (-IN)
unnamed: U5.6 (-IN_B), U5.7 (OUT_B)

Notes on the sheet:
SENSOR PT100
SALIDAS HACIA B-BOX
SENSOR SM-50
ALIMENTACION Y PROTECCIONES
ENTRADA DE SENSORES
REFERENCIAS ANALOGICAS

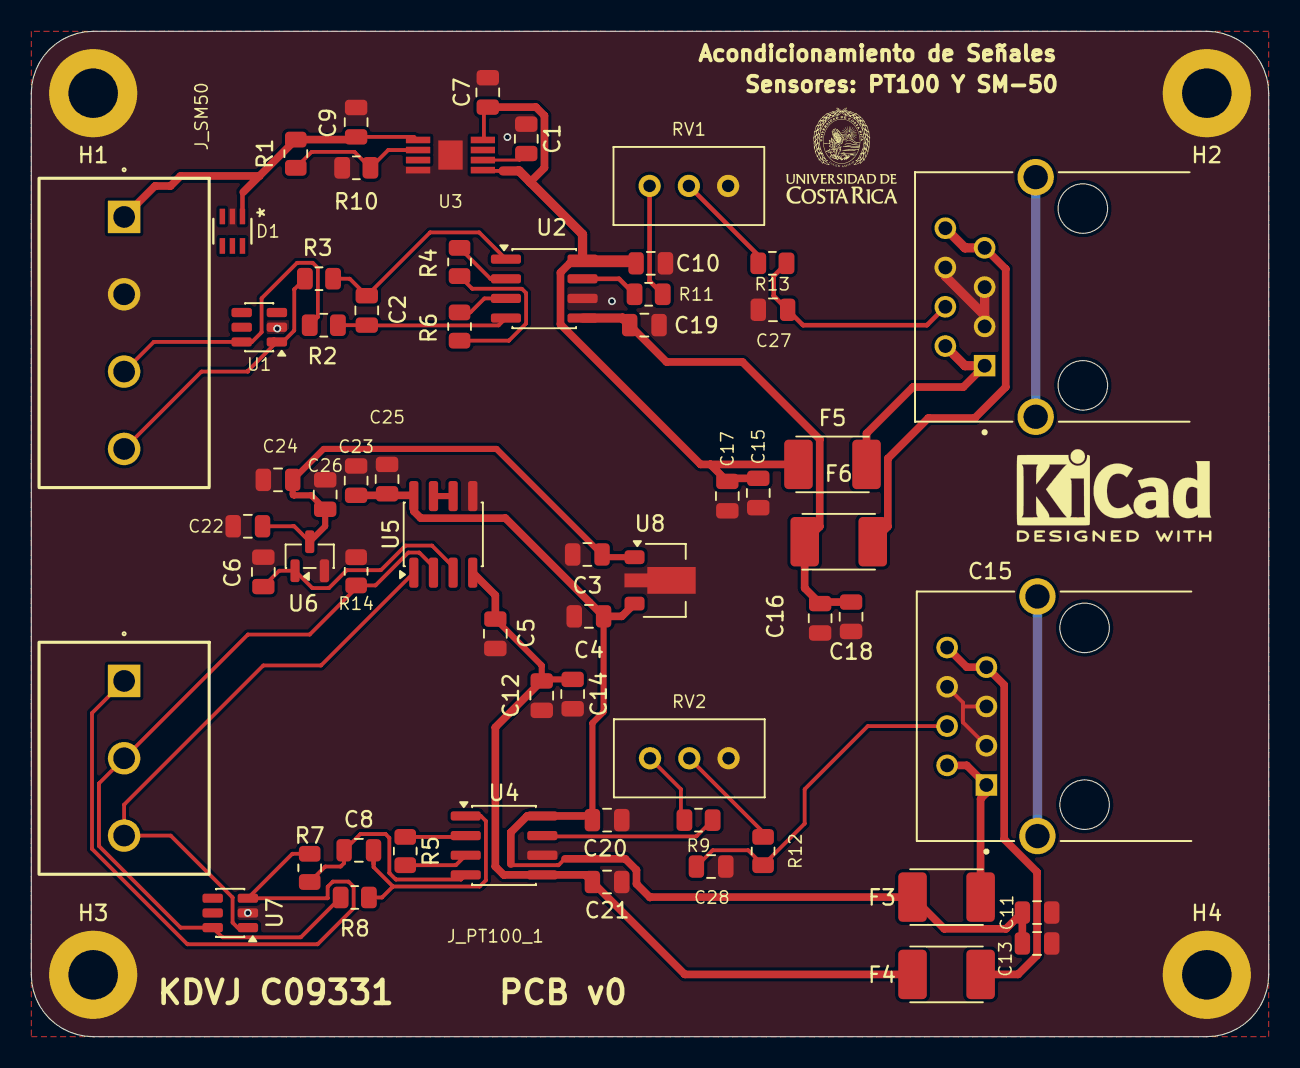
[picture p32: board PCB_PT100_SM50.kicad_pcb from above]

Board: 2 copper layers, 80.0 x 65.0 mm, 65 parts (0 on the bottom side), 39 nets.

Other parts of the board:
H1, H2, H3, H4: MountingHole_3.2mm_M3_ISO7380_Pad

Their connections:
GND: H1.1, H2.2, H3.3, H4.4; also elsewhere on the board

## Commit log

2026-06-24 Prepare PCB project for GitHub delivery
    [08055C104K4T2A_AVX_0805_100nF.step, 08055C333KAT2A_AVX_0805_33nF.step, 2250066-1.step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]
2026-06-26 Publish final PCB project
    [AST0250404.stp, PCB_PT100_SM50.kicad_pcb, PCB_PT100_SM50.kicad_sch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]
2026-06-26 Correct simulation figures
    [pt100_sweep_ng_20260625.csv, sm50_sweep_positive_ng_20260625.csv]
2026-06-26 Update PCB 3D front view
2026-06-27 Update LTspice schematics and fabrication outputs
    [PCB_PT100_SM50.kicad_pcb, PCB_PT100_SM50.kicad_sch, pt100_sweep_ng_20260625.csv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]
2026-06-27 Fix PCB 3D view orientation
2026-06-27 Fix PCB editor image crop
2026-06-27 Arreglando errores de ortografíia en le README
    Corrige errores de acentuación y ortografía en el README.
2026-06-27 Fix PCB 3D image orientation
2026-06-27 Center PCB 2D image in README
2026-07-10 Add final sensor calculations and references
    [calculos_PT100_SM50_VALORES_ACTUALES_v2.csv]
2026-07-10 Set PCB 3D image to frontal view
2026-07-10 Use provided PCB 3D top render
2026-07-10 Restaurar version SM-50 0-5V
    [PCB_PT100_SM50.kicad_pcb, PCB_PT100_SM50.kicad_sch, calculos_PT100_SM50_VALORES_ACTUALES_v2.csv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]
2026-07-10 Actualizar figuras SM-50 0-5V
2026-07-10 Reemplazar render 3D del PCB
2026-07-10 Documentar limite ADC B-Box +/-5V
    [calculos_PT100_SM50_VALORES_ACTUALES_v2.csv]
2026-07-10 Actualizar salida bipolar SM-50
    [calculos_PT100_SM50_VALORES_ACTUALES_v2.csv, sm50_sweep_bipolar_ng_20260629.csv, sm50_sweep_positive_ng_20260625.csv]
2026-07-10 Agregar reporte IEEE del acondicionamiento PCB
2026-07-10 Renombrar reporte formal PCB
2026-07-10 Ampliar justificacion de componentes del reporte
2026-07-10 Ordenar flujo de referencias
2026-07-11 Correct PCB trace width report and fabrication files
    [PCB_PT100_SM50.kicad_pcb]
